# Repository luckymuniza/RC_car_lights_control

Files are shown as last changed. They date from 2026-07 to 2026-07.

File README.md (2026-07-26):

# RC Car Lights Control

Lighting controller for a large-scale RC truck. An RP2040 board sits between the
FlySky receiver and a **MFC-03** multi-function unit, reads the receiver's **iBUS**
stream directly, and drives the vehicle's LED lighting from it — while still letting the
MFC-03 keep control of the things it does best (sound, engine start-up sequence,
turn-signal timing, brake detection).

The MCU is both a *consumer* of the MFC-03 (it watches the MFC's own light and
turn-signal outputs) and a *producer* for it (it synthesises a servo signal into the MFC's
light channel so the MFC's internal "lights on" state stays in sync).

```
FlySky FS-i6X  ──2.4GHz──►  FS-iA6B RX ──┬── iBUS (UART, 115200) ──► RP2040 ──► LED outputs
                                          │                            ▲  │
                                          └── (channels) ──► MFC-03 ───┘  │
                                                                ▲          │
                                                                └──────────┘
                                                            synthesised servo signal
```

## Repository layout

| Path | Contents |
| --- | --- |
| `FW/` | Firmware — C, Raspberry Pi Pico SDK ≥ 2.1.0 |
| `HW/rccarcontrol/` | KiCad 9 project: schematic, PCB, gerbers, DRC report |
| `doc/` | MFC-03 manual, FS-i6X manual, output mapping spreadsheet, wiring manual |
| `sim/` | Multisim analog simulation (`Design1.ms14`) |

## Hardware

The board is built around a **USB-C RP2040 "Pico C" module** (`HW/.../rccarcontrol.kicad_sch`,
symbol `Pico_type_c`). Note this is *not* pin-compatible with a genuine Raspberry Pi Pico:
the module breaks out **GPIO29 on pad 35** and **GPIO23 on pad 37**, where a stock Pico has
`ADC_VREF` and `3V3_EN`. The firmware drives both of those pins, so it will not run
correctly on a stock Pico without remapping `FRONT_RAMP_LIGHT_OUT_PIN` and
`TURN_R_FRONT_OUT_PIN`.

Interfacing:

- **Inputs from the MFC-03** go through `EL3H7` optocouplers (U2–U8), so they are
  **active-low** and the firmware enables internal pull-ups on all of them.
- **Outputs** drive `IRLML0030` N-MOSFETs. Solder jumpers `JP3`–`JP7` select `+7V2_LED` or
  `+5V_LED` per LED group; `JP1`/`JP2` bring the receiver / external supply onto `+5V`.
- **Reverse light** (`REVERSE_LIGHT_IN`, opto U1) is wired straight to Q1/Q2 in hardware and
  never reaches the MCU — there is intentionally no firmware for it.

### Pin map

Verified against the PCB netlist. "Pad" is the module pad number.

**Outputs**

| GPIO | Pad | Net | Firmware | Type |
| --- | --- | --- | --- | --- |
| 0 | 1 | `LED_POWER` | `lights.c` | digital — master LED supply gate |
| 1 | 2 | `LOW_BEAM_OUT` | `lights.c` | digital |
| 2 | 4 | `HIGH_BEAM_OUT` | `lights.c` | digital |
| 3 | 5 | `FOG_LIGHT_OUT` | `lights.c` | digital |
| 4 | 6 | `AUX_1_OUT` | `aux1.c` | PWM slice 2A, 50 Hz servo, **inverted** polarity |
| 5 | 7 | `AUX_2_OUT` | `main.c` | digital — toggled every loop pass (loop-rate test point) |
| 6 | 9 | `TURN_R_PWM_OUT` | `turn_light.c` | PWM slice 3A, 2 kHz |
| 7 | 10 | `TURN_L_PWM_OUT` | `turn_light.c` | PWM slice 3B, 2 kHz |
| 8 | 11 | `TURN_L_FRONT_OUT` | `turn_light.c` | digital — short front-indicator pulse |
| 9 | 12 | `SEARCH_LIGHT_OUT` | `lights.c` | digital |
| 10 | 14 | `REAR_LIGHT_PWM_OUT` | `rear_light.c` | PWM slice 5A, 500 Hz |
| 11 | 15 | `SIDE_LIGHT_1_OUT` | `lights.c` | digital |
| 12 | 16 | `SIDE_LIGHT_2_OUT` | `lights.c` | digital |
| 13 | 17 | `RX_PWM_OUT` | `to_mfc.c` | PWM slice 6B, 50 Hz servo → MFC light channel |
| 14 | 19 | `BEACON_SMALL_PWM_OUT` | `beacons.c` | PWM slice 7A, 50 Hz servo |
| 15 | 20 | `BEACON_BIG_PWM_OUT` | `beacons.c` | PWM slice 7B, 50 Hz servo |
| 23 | 37 | `TURN_R_FRONT_OUT` | `turn_light.c` | digital |
| 25 | — | on-board LED | `main.c` | boot-blink only |
| 27 | 32 | `DAY_LIGHT_OUT` | `lights.c` | digital — on permanently after init |
| 28 | 34 | `POSITION_LIGHT_OUT` | `lights.c` | digital |
| 29 | 35 | `FRONT_RAMP_OUT` | `lights.c` | digital |

**Inputs** (all pulled up, active low)

| GPIO | Pad | Net | Firmware | Purpose |
| --- | --- | --- | --- | --- |
| 16 | 21 | `TURN_R_IN` | `turn_light.c` | MFC right indicator |
| 17 | 22 | `LIGHT_0_IN` | `lights.c` | configured, **not read** |
| 18 | 24 | `LIGHT_1_IN` | `lights.c` | MFC light state + start-up flash pattern |
| 19 | 25 | `LIGHT_2_IN` | `lights.c` | configured, **not read** |
| 20 | 26 | `LIGHT_3_IN` | `lights.c` | configured, **not read** |
| 21 | 27 | `RX_SBUS_IN` | `ibus.c` | UART1 RX — iBUS, 115200 8N1 |
| 22 | 29 | `TURN_L_IN` | `turn_light.c` | MFC left indicator |
| 26 | 31 | `REAR_BRAKE_IN` | `rear_light.c` | ADC0 — MFC rear/brake light level |

### Transmitter channel map

From `FW/ibus.h` (`ibus_channel`), 1-based as shown on the FS-i6X:

| Ch | Name | Used by |
| --- | --- | --- |
| 1 | Steering | — (passes to MFC directly) |
| 2 | MFC light channel | `to_mfc.c`, `aux1.c` |
| 3 | Throttle | — |
| 4 | Throttle X | — |
| 5 | Mode switch | `aux1.c` |
| 6 | Beacon switch | `beacons.c` |
| 7 | Gear switch | — |
| 8 | Light switch | `lights.c` |
| 9 / 10 | Pot A / Pot B | — |

Channels 1, 3, 4, 7 and the pots are declared but not consumed by the firmware.

## Firmware

### Structure

Cooperative, non-blocking super-loop. Every module exposes `*_init()` (called once) and
`*_service()` (called every pass, returns immediately). No RTOS, no blocking delays after
start-up, no dynamic allocation. All timing uses `time_us_32()` deadlines compared as
signed differences, so 32-bit wrap is handled correctly.

| Module | Responsibility |
| --- | --- |
| `main.c` | Boot blink, init order, super-loop |
| `ibus.c` | iBUS frame decoding — the only interrupt-driven part |
| `lights.c` | Light-state machine, side lights, MFC light-state sync, start-up flash replay |
| `turn_light.c` | Indicator soft fade-in / fade-out driven by MFC edges |
| `rear_light.c` | Tail / brake light PWM, ADC brake detection |
| `beacons.c` | Rotating beacons, fog + search light, beacon configuration mode |
| `to_mfc.c` | Synthesised servo output back into the MFC light channel |
| `aux1.c` | Diverts the light channel to an auxiliary servo output (crane) |
| `switch.h` | Shared 3-position-switch state machine constants |

### iBUS decoder

`ibus.c` decodes the standard 32-byte FlySky iBUS servo frame:

```
0x20 0x40 <14 × uint16 LE channel values> <uint16 LE checksum>
```

The checksum is validated by summing all 32 bytes and requiring `0xFFFF`. Frame
synchronisation is done by **inter-byte gap**, not by header alone: a byte arriving more
than `SBUS_NEXT_FRAME_TIMEGAP` (3 ms) after the previous one is treated as a frame start.
Frames arrive roughly every 7 ms and each takes ~2.7 ms, so the gap is unambiguous.

The ISR writes into `channel_data`; `ibus_service()` copies it to `channel_data_saved`
with interrupts disabled, and `ibus_get_channel()` reads only the snapshot.

### Light state machine (`lights.c`)

Channel 8 acts as a momentary 3-position switch. Short pull **up** steps forward, holding
up for >1 s steps back:

```
OFF ──► POSITION ──► LOW_BEAM ──► HIGH_BEAM ──► RAMP
    ◄──          ◄──          ◄──           ◄──          (hold >1 s)
```

Pushing **down** flashes the front ramp light for as long as it is held.

Side lights (`SIDE_LIGHT_1/2`) have their own state: off, on with the position lights, a
double-flash alternating beacon pattern (when the rotating beacons are on), or a slow
0.5 s blink to indicate beacon-configuration mode.

### MFC light-state sync

The MFC-03 beeps when the engine is switched off with its lights still on, so its internal
state must track the real one. `update_lights_in_mfc()` compares `l_state` against
`LIGHT_1_IN` and, when they disagree, asks `to_mfc.c` to emit one 100 ms pulse train on the
synthesised light channel — the equivalent of one stick flick. It repeats every 0.5 s until
the states match.

### Start-up flash replay

On engine start the MFC-03 flashes its light output rapidly. `detect_starting_seq()`
detects this (edges closer than 25 ms apart), records the on/off durations into a 64-entry
ring buffer — duration in bits 0–14, level in bit 15 — and replays them onto `LED_POWER`
so the real headlights flicker in step with the MFC's simulated start-up. While the replay
is active, MFC light-state sync is suspended.

### Turn signals

The MFC drives the blink timing; the firmware only reshapes it. On each falling edge of
`TURN_L_IN` / `TURN_R_IN` it pulses the front indicator hard for 100 ms and simultaneously
ramps the PWM channel up (100 counts / 10 ms), holds at full for 100 ms, then ramps down
(50 counts / 7.5 ms) — roughly a 600 ms incandescent-style fade. Re-triggering is ignored
while a fade is still running.

### Rear / brake light

`REAR_BRAKE_IN` is sampled on ADC0 through a 32-sample moving average. Below
`REAR_LIGHT_BRAKE_LEVEL` the tail light PWM goes to full (brake); otherwise it follows the
main light state at 25 % duty, or off.

### Beacons

Two servo-protocol beacon outputs, driven as if by a stick:

- **Short pull up** — both beacons on, side lights switch to the alternating flash pattern.
- **Hold up >1 s** — both off. The small beacon has to be cycled through all four of its
  internal modes to reach off, which `beacon_small_off()` does with eight 50 ms pulses.
- **Hold up >5 s** — enter configuration mode: big beacon on, side lights blink slowly. In
  config, short up = next mode, short down = next brightness, hold up >5 s = exit.
- **Short pull down** — cycles the rear search light and the fog light. Hold down >1 s
  turns both off. The fog light only comes on if the main lights are on.

### Auxiliary output

When channel 5 is above 1800, `aux1.c` mirrors the channel-2 value onto `AUX_1_OUT`
(inverted polarity) for a crane servo, and tells `to_mfc.c` to park the MFC light channel at
centre so the MFC ignores it.

## Building

Requires the Raspberry Pi Pico SDK **2.1.0 or later**, `arm-none-eabi-gcc`, CMake ≥ 3.12
and `picotool`.

```sh
export PICO_SDK_PATH=/path/to/pico-sdk
cd FW
cmake -B build -DCMAKE_BUILD_TYPE=Debug
cmake --build build
```

Output is `build/car_lighting.uf2` (plus `.elf`, `.bin`, `.hex`, `.map`). The build prints
memory usage and a section size summary.

`CMakeLists.txt` hardcodes `picotool_DIR` to a local absolute path; override it with
`-Dpicotool_DIR=...` or edit it if picotool lives elsewhere. `stdio` over both USB and UART
is disabled — GPIO0/GPIO1 are used as light outputs, so UART0 is unavailable. To get printf
debugging you must free those pins first.

## Flashing

Hold `BOOTSEL` while plugging the board in and copy the `.uf2` to the `RPI-RP2` drive.

`FW/up.bat` automates this on Windows: it pokes the USB CDC port at 1200 baud to force the
board into BOOTSEL, finds the `RPI-RP2` volume and copies the image. It references helper
tools under `f:\_Work\_Programing\rpi\` and expects the artefact in
`cmake-build-debug-system-arm\`, so the paths need adjusting for the current build
directory before it will work.

## Known limitations

- **No receiver failsafe.** `ibus_get_channel()` returns the last valid frame forever. If
  the link drops, the lighting freezes in its last state and the synthesised MFC channel
  keeps repeating a stale value.
- **Boot blocks on iBUS.** `main()` spins in `while (!ibus_data_valid())` before any
  outputs are initialised, so with no receiver signal the board never leaves start-up.
- **No watchdog.**
- `LIGHT_0_IN`, `LIGHT_2_IN`, `LIGHT_3_IN` are wired and configured but unused.

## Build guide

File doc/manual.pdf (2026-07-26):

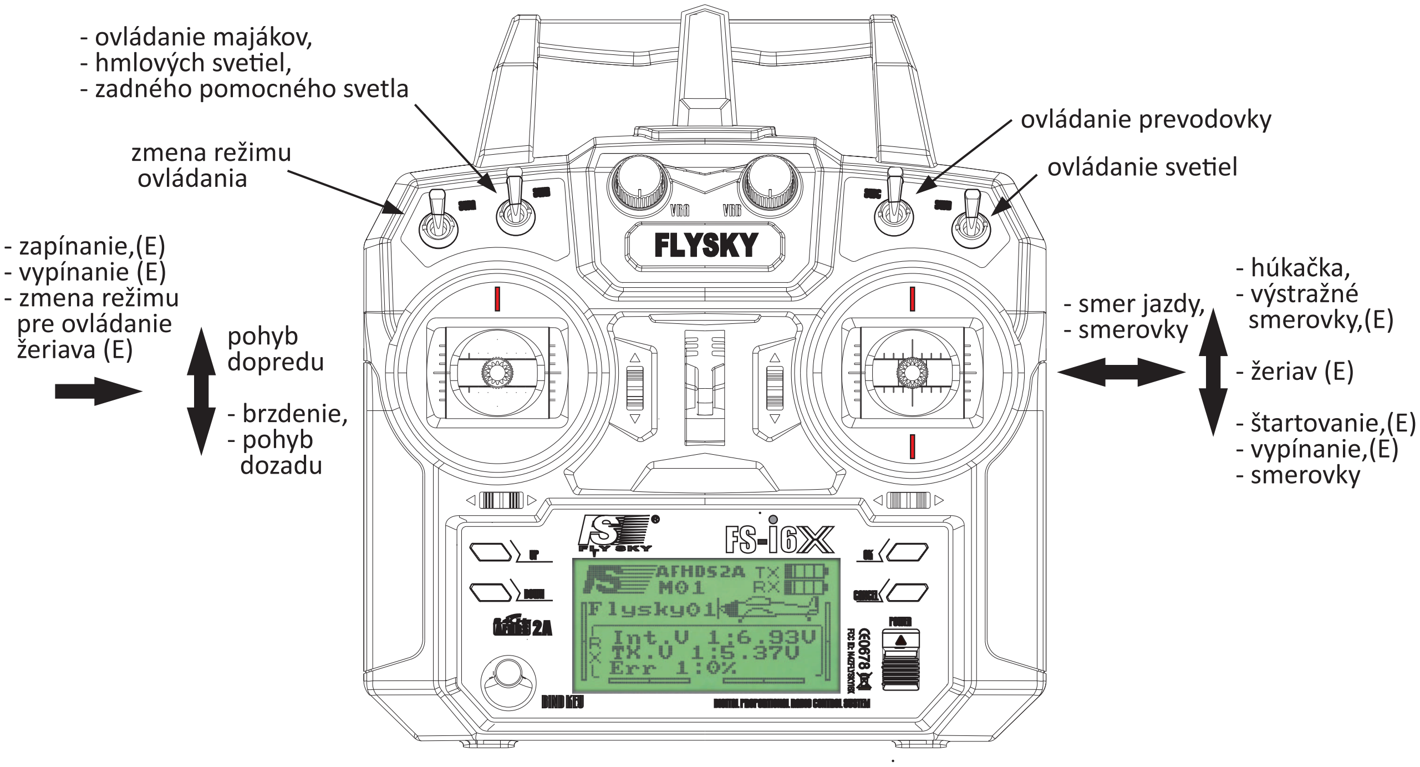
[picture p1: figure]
ž mena re imu; ovl dania á; - ovládanie majákov, - hmlových sve%el, - zadného pomocného svetla; ovládanie prevodovky; ovládanie sve%el; - smer jazdy, - smerovky; - húkačka, - výstražné smerovky,(E); - žeriav (E); - štartovanie,(E) - vypínanie,(E) - smerovky; - zapínanie,(E) - vypínanie (E) - zmena režimu pre ovládanie; žeriava (E); pohyb; dopredu; - brzdenie, - pohyb dozadu

Z | ž | á | . mena re imu ovl dania
Normálny režim - | loha od seba. V tomto režime sa auto normálne ovláda (pohyb dopredu, po
dozadu, a ostatné funkcie)

Extra režim 1 - loha neutrálna. vo vysielači je označený ako SPORT. po
V tomto režime majú niektoré kniple ďalšie funkcie. V popise hore sú označené (E)

Extra režim 2 - loha smerom k sebe. To isté ako Extra režim ale v tomto režim pravý knipel po ovláda priamo žeriav. Toto funguje vtedy ak by sa pripojilo ovládanie žeriavu do rozširujúceho modulu, nie do MFC-03 ako to je. Ak je ovládanie pripojené do MFC-03 ovláda sa cez Extra režim 1.

## Z prevodového stupňa. mena

Stupeň 1

Stupeň 2

Stupeň 3

## Popis ovládania sve$el pre Volvo Fh16 s modulom MFC-03

## Ovládanie majákov, hmlových sve$el, zadného pomocného svetla, sve!el

> 0.01s ON
1s> | OFF | zapnu$e - podržať v polohe min 0,01s a vrá%ť späť vypnu$e - podržať v polohe rovnakej ako pri zapínaní min 1s a vrá%ť späť,
Majáky | polohe k sebe - podržať v | vrá%ť späť. Pri zapnutých majákoch blikajú striedavo
bočné svetlá 1 a 2 (4ks + 4ks) na jednej a druhej strane
Hmlové a Zadné pomocné svetlá | v polohe odseba - podržať | vrá%ť späť
Pri zapínaní sa zapínaju svetlá v takomto poradí: 1.iba zadné pomocné
2.iba hmlové
3 hmlové + zadné pomocné
Ak nesvie%a hlavné svetlá (aspoň pozičné) nedajú sa hmlové zapnúť
Pozičné, stretávacie, diaľkové, rampa | v polohe k sebe - podržať | vrá%ť späť
Pri zapínaní sa postupne rozsvecujú svetlá v takomto poradí:
1. pozičné
2. + stretávacie + zadné + bočné
3. + diaľkové
4. + horná rampa
Postupným zapínaním sa rozsvecujú ďalšie svetlá. Pri vypínaní sa zhášajú v opačnom poradí.

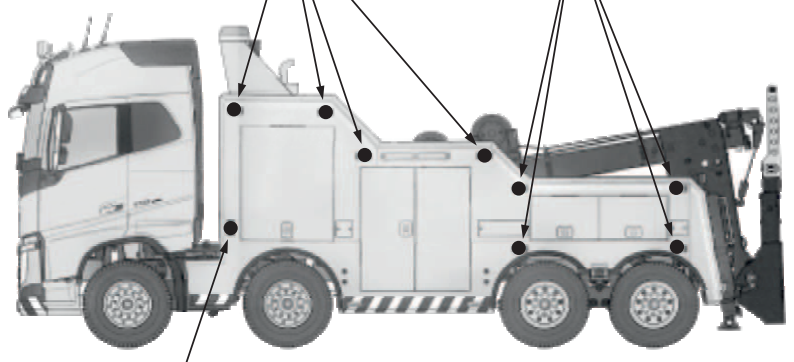
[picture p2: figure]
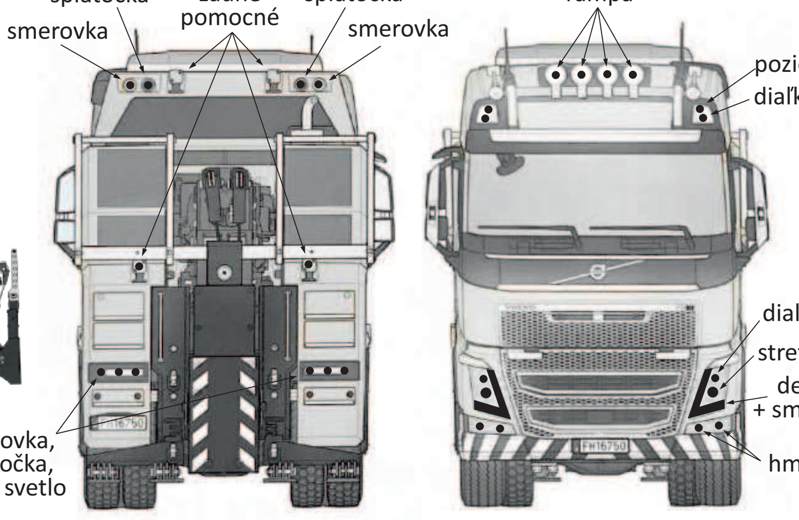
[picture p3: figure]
pomocné; smerovka

Rampa ako svetelná húkačka | v polohe od seba - podržať | . Svie%počas držania vypínača v polohe.
Konfigurácia veľkého majáku | polohe k sebe - podržať v | viac ako 5s. Maják sa zapne a blikajú
bočné svetlá. Jednotlivé módy | ó | sa potom prepínajú krátkym podr - 18 m dov | žaním ( 0,01s) v >
polohe k sebe a jas - 3 úrovne sa prepínajú krátkym podržaním ( 0,01s) | . > | polohy od seba
Ukončenie konfigurácie sa dosiahne podržaním v | na viac ako 5s. Maják a polohe k sebe
bočné svetlá prestanú blikať.
Mód | Jas
> | ON 5s Konf.
> | OFF 5s Konf.

## Rozmiestnenie svie$diel

bočné
svetlá 1

zadné

bočná
smerovka

spiatočka
spiatočka

smerovka,
spiatočka,
zadné svetlo

rampa

pozičné
diaľkové
bočné
svetlá 2

denné
+ smerovka

stretávacie

hmlové

diaľkové

norm lá ny
režim
Štartovanie - normálny režim zapnutý, ravý knipel k sebe. Ak sa posunie knipel p na doraz a podrží určitú dobu motor naštartuje, ak sa podrží niekde medzi krajnou polohou a neutrálnou polohou motor bude štartovať pokiaľ sa knipel neposunie do krajnej polohy. Pred štartovaním je potrebné vykonať zapnu%e zapaľovania ak bolo predtým vypnuté. Po prvom zapnu* prijímača nie je potrebné ,môže sa hneď štartovať.

extra
režim
Vypnu$e motora - extra režim zapnutý, súčasne ľavý knipel doprava, ravý p knipel k sebe a uvoľniť. Ak ostali zapnuté svetlá, modul pípa.

Zapnu$e zapaľovania po vypnu' - to isté ako vypnu%e motora, extra režim
zapnutý, ľavý knipel doprava, ravý knipel k sebe a uvo p | ľniť. Je nutné vykonať
pred štartovaním ak sa predtým vykonalo vypnu%e motora.

Pred spustením - vypínače musia byť v polohe od seba a ľavý knipel v polohe k sebe. Inak vysielač nedovolí ovládanie. Tie dva ktoré sa vracajú do neutrálnej polohy sa %ež musia podržať v polohe odseba.

Smerovky - normálny režim, najprv pravý knipel úplne k sebe a uvoľniť. Potom posunúť do tej strany na ktorú má svie%ť smerovka. Ak sa posunie knipel úplne do krajnej polohy, doľava alebo doprava, smerovka sa vypne keď sa posunie do neutrálu. Keď sa posunie len do polovice ustane zapnutá. Vypne sa opätovným pri%ahnu*m knipla k sebe.

norm lá ny
režim

1

3 | 3
| 2
1 | 2

1

2

1 2

Výstražné smerovky - Extra režim, Pravý knipel od seba a uvoľniť. to isté zopakovať pre vypnu%e smeroviek. ¹ 2

extra
režim

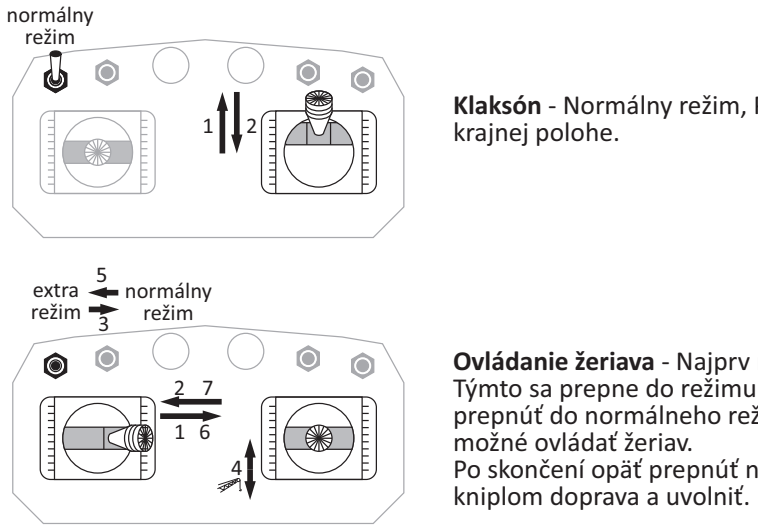
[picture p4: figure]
krajnej polohe. ¹; norm lá ny režim; možné ovládať žeriav.; kniplom doprava a uvolniť.; extra režim

Klaksón - Normálny režim, Pravý knipel od seba. Klaksón trúbi pokiaľ je knipel v

Ovládanie žeriava - Najprv nastaviť extra režim. Ľavý knipel doprava a uvoľniť. Týmto sa prepne do režimu ovládania žeriavu pravým kniplom. Extra režim prepnúť do normálneho režimu a pravým kniplom od seba a k sebe je potom

Po skončení opäť prepnúť na extra režim a ukončiť ovládanie žeriavu ľavým

Ovládanie ďalších funkcií | MFC-03 - funkcie

Ovládanie žeriava - Je možné aj priamo v režime Extra 2 ale je potrebné inak zapojiť ovládanie žeriavu.

extra
režim 2

Zmena zvuku smeroviek - Extra režim a zapnúť výstražné smerovky. Potom pravý knipel k sebe, doľava a uvoľniť. Takto sa prepne iný typ zvuku smeroviek. Na výber sú dva typy.

extra
režim

1

2

Zmena klaksónu - Extra režim. Potom ľavý knipel doľava a uvoľniť. Takto sa prepne iný typ zvuku klaksónu.
Na výber sú dva typy.

extra
režim

1

2

Odfúknu$e - Normálny režim. Pravý knipel držať k sebe. Potom ľavý knipel kúsok (10%) k sebe a uvoľniť. Môže sa zopakavať.

1

2

norm l á ny
režim

10%

3

norm l á ny
režim

Režim spojky - Normálny režim. Pravý knipel funguje ako spojka, čím je viac k sebe tým je akoby spojka viac stlačená - motor ide naprázdno, rýchlejšie ide do otáčok (zvuk) ako keď je v neutrálnej polohe.

Nastavenie vysielača.

Keďže MFC-03 dokáže spracovaťsignály len zo 4 kanálov. Pre prepnu%eďalších funkcií týchto 4 kanálov sa využíva toho že v normálnom režime sú hodnoty kanálov od -100% po + 100%. Ale ak sa použije trim a posunie sa do krajnej polohy potom hodnota kanálu môže ísť až napr. od -120% po +120%. Takže ak MFC-03 zis* že vysielač posiela hodnotu 120% pova uje ž ju za ďalšiu možnosť alebo prepnu%e inej funkcie. Vysielač FLYSKY má digitálne trimre a prepínať trimrami %eto ďalšie funkcie by bolo komplikované - je potrebné čo najrýchlejšie nastaviť trim do krajnej polohy. Preto sa využívaju dvojité výchylky na vysielači. Na vysielači sú nastavené dva režimy NORMAL a SPORT ktorý má nastavené pre konkrétne kanály dvojité výchylky. V tomto prípade pre ľavý knipel 4. kanál a pravý knipel 1. a 2. kanál. Takže ľavý vypínač - prepínač režimu, v normalnom režime na vysielači nastavý režim NORMAL a v Extra 1 je prepnutý na vysielači režim SPORT a v Extra 2 je%ežrežim SPORT. V režime NORMAL sú hodnoty kanálo 1,2,4 pri plnom vychýlení knipla len
do 75% | %. . V režime Extra do 100 | Čiže ak by bol zapnuty režim Extra tak ak by sa s kniplom išlo len do 75% vychýlenia
bolo by to ako v režime NORMAL. Napr. klaksón a výstražné smerovky. Pravý knipel od seba sa zapínajú výstražné smerovky ale aj klaksón. Lenže klaksón je v normálnom režime 75% hodnota, a smerovky v Extra režime 100%. Takže ak je zapnutý extra režim a knipel sa vychýli do 75% zatrúbi klaksón.
K.4 | K.1

K.2

K.3

K.5 | K.6 | K.7 K.8
K.9 | K.10

Rozmiestnenie kanálov na vysielači - MÓD 2 Vo vysielači nastavené v menu SYSTÉM: S!ck Mode -> MODE 2
RX setup -> Output mode -> PWM, I-BUS AUX switches -> SWA ON, SWB ON, SWC ON, SWD ON,
VrA ON, VrB ON,
CH 10

v menu FUNCTION SETUP:
Reverse -> všetky kanály NORMAL
End Points - v > šetky kanály 100%, pre kanál 7 - servo prevodovky, treba nastaviť koncové body podľa potreby AUX channels - Channel 5 - SwA >
Channel 6 - SW B
Channel 7 - SW C
Channel 8 - SW D
Channel 9 - VrA
Channel 10 -VrB
Subtrim -> v | 0 šetky kanlály
Dual rate - K.1, 2, 4 re > | žim NORMAL rate 75%
režim SPORT rate 100%
Asign Switches - | - > Fly mode > SwA
prep | . V ínanie módu NORMAL / SPORT | popise Normálny režim a Extra režim. Extra režim 2 je vo
vysielači to isté ako ako Extra režim, rozlišuje sa až v prídavnom module).
Ostatn nastavenia é | štandartné.
Pre MFC-03 je potrebné urobiť kalibráciu rozsahu kanálov v normálnom režime - %eto sú pre MFC-03 100%
v chylky ý . Podľa manuálu MFC-03. Podržať spínač na MFC-03 medzi 1 až 3 s - začnú blikať smerovky. potom posunúť z krajnej polohy ľavý knipel zhora dole, potom ľavý knipel zprava do ľava, pravý knipel zhora dole a pravý knipel z prava do ľava. Potom prestanú blikať smerovky, tak ešte raz stlačiť tlačítko. Výchylky pre trim nie je potrebné kalibrovať (a ťažko by sa to v takejto konfigurácii s digitálnymi trimrami).

## Pomocn modul ý

Pomocný modul je na to aby bolo možné použiť viac funkcií vysielača, a jednoduchšie ovládanie. Takto sa využívajú všetky vypínače. Tie sú všetky trojpolohové. Potenciometre sa nevyužívajú (Takže ešte ostali volné kanály 9,10). MFC-03 funguje len na zvuk, sekvencie pri štartovaní, brzdenie, spiatočka, smerovky. Ovládanie majákov a sve%el je cez prídavný modul. Ale je zachované blikanie sve%el pri štartovaní a pípanie pri vypnu* motora. Smerovky pre predné svetlá sú%ežsynchronizované s MFC-03. Keďže je teraz viac lediek tak všetky spína prídavný modul. Aby bolo spínanie sve%el synchronizovné s MFC-03 prídavný modul emuluje spínacie sekvencie sve%el v MFC-03, takže zapnu%e sve%el v MFC-03 a v prídavnom module je synchronizované. To je len kôli tomu že keď sa motor vypne tak pípa že svie%a svetlá. a ešte kvôli tomu efektu že keďsa štartuje tak sa simuluje pokles napa%a - to robí ten MFC-03. Ěšte je pridaný taký efekt že smerovky blikajú ako žiarovky, pomaly sa zhášajú. Pre veľký maják sa dá zmeniť mód aj jas.Malý maják má %ež 4 módy blikania lenže tam je problém s vypínaním nevypína sa ako ten veľký maják hodnotou kanála ale prepínaním módov. Na začiatku je hneď zapnutý takže treba poprepínať všetky 4 módy aby zhasol - lepšie by bolo ho vypínať napájaním. Ale to vypnu%e robí automa%cky ten modul takže neni toto treba absolvovať. Len užsa nedá vybrať mód. Je tam mód 1, taký že ako keby sa točilo svetlo vnútri majáku.
Ostali ešte dva pomocné výstupy voľné AUX1, AUX2, môžu niečo spínať ak by bolo treba. Hodnota všetkých kanálov z vysielača sa získava z prijímača cez I-BUS zbernicu.
Napájaný je z hlavnej batérie a je ešte doplnený zdroj aby udržiaval stále napä%e 7,2V aj keď napä%e batérie klesne na nižšiu hodnotu. zapínaťsa nemusí, zapne sa keďsa zapne MFC-03.

Schéma zapojenia.

## MFC-03

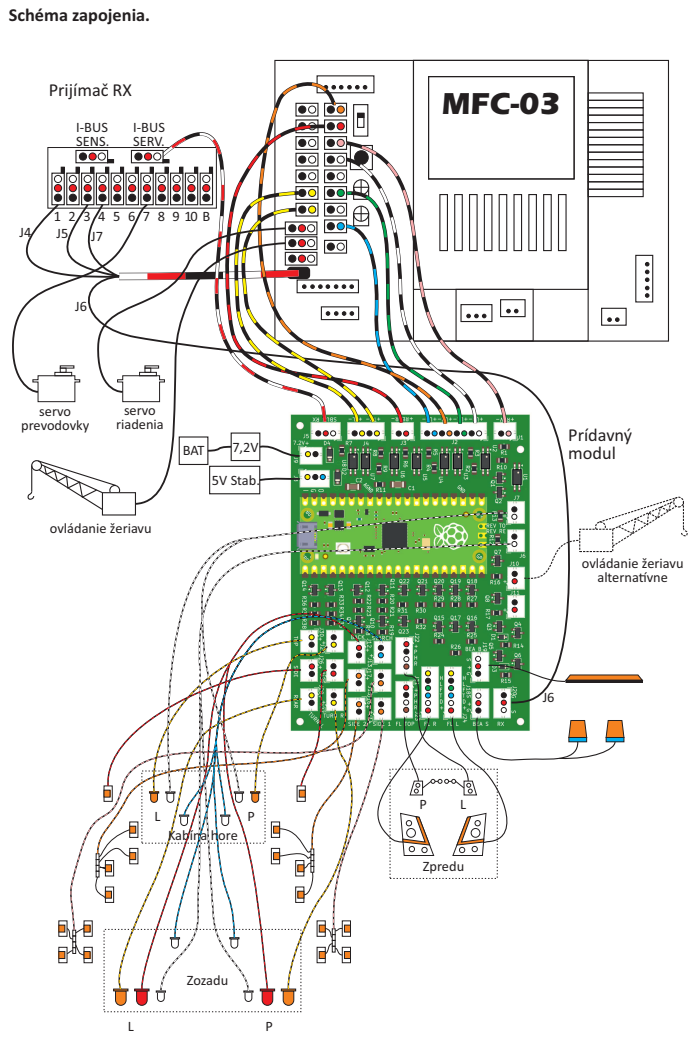
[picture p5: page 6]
I-BUS SERV.; Prijímač RX; 5V Stab.; Kabína hore; Zozadu; Zpredu; servo prevodovky; servo riadenia; ovl anie eriavu ád; Prídavný modul; alterna*vne; BAT; I-BUS SENS.

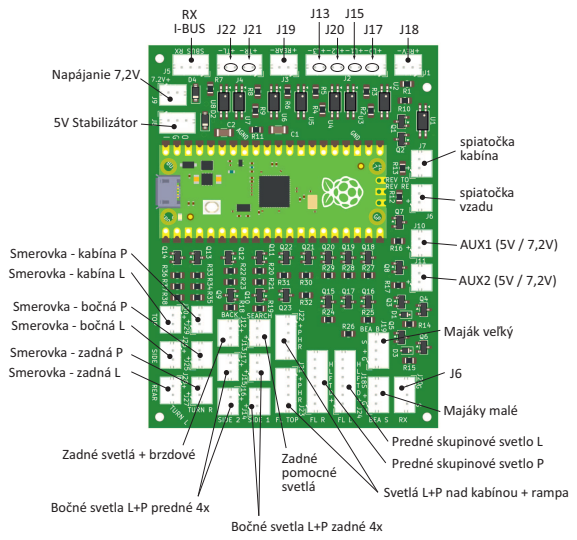
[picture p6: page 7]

Svetlá L+P nad kabínou + rampa

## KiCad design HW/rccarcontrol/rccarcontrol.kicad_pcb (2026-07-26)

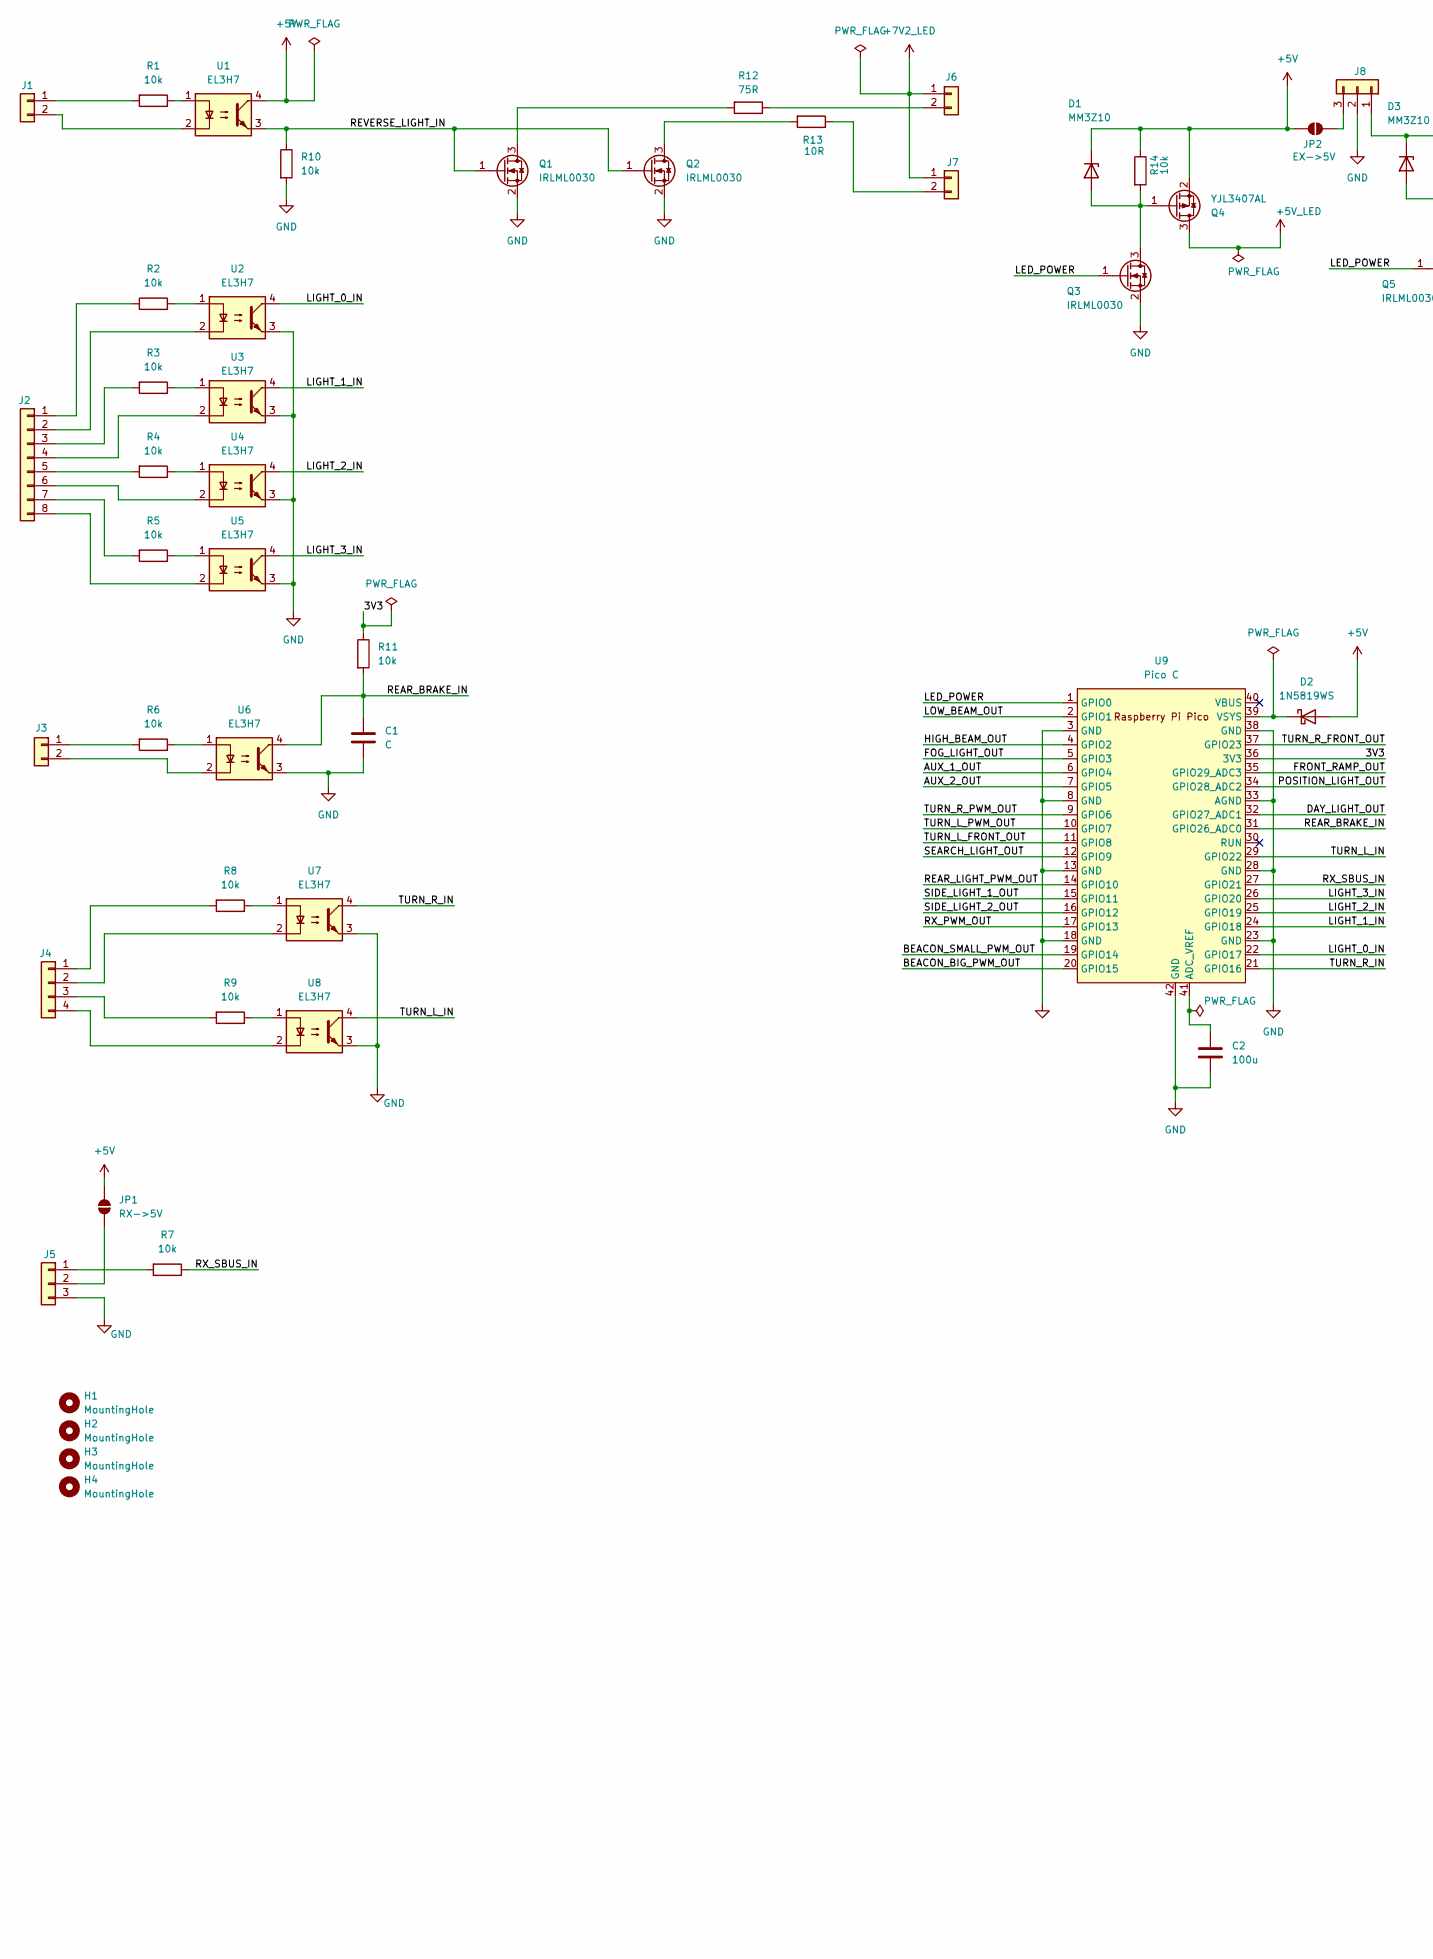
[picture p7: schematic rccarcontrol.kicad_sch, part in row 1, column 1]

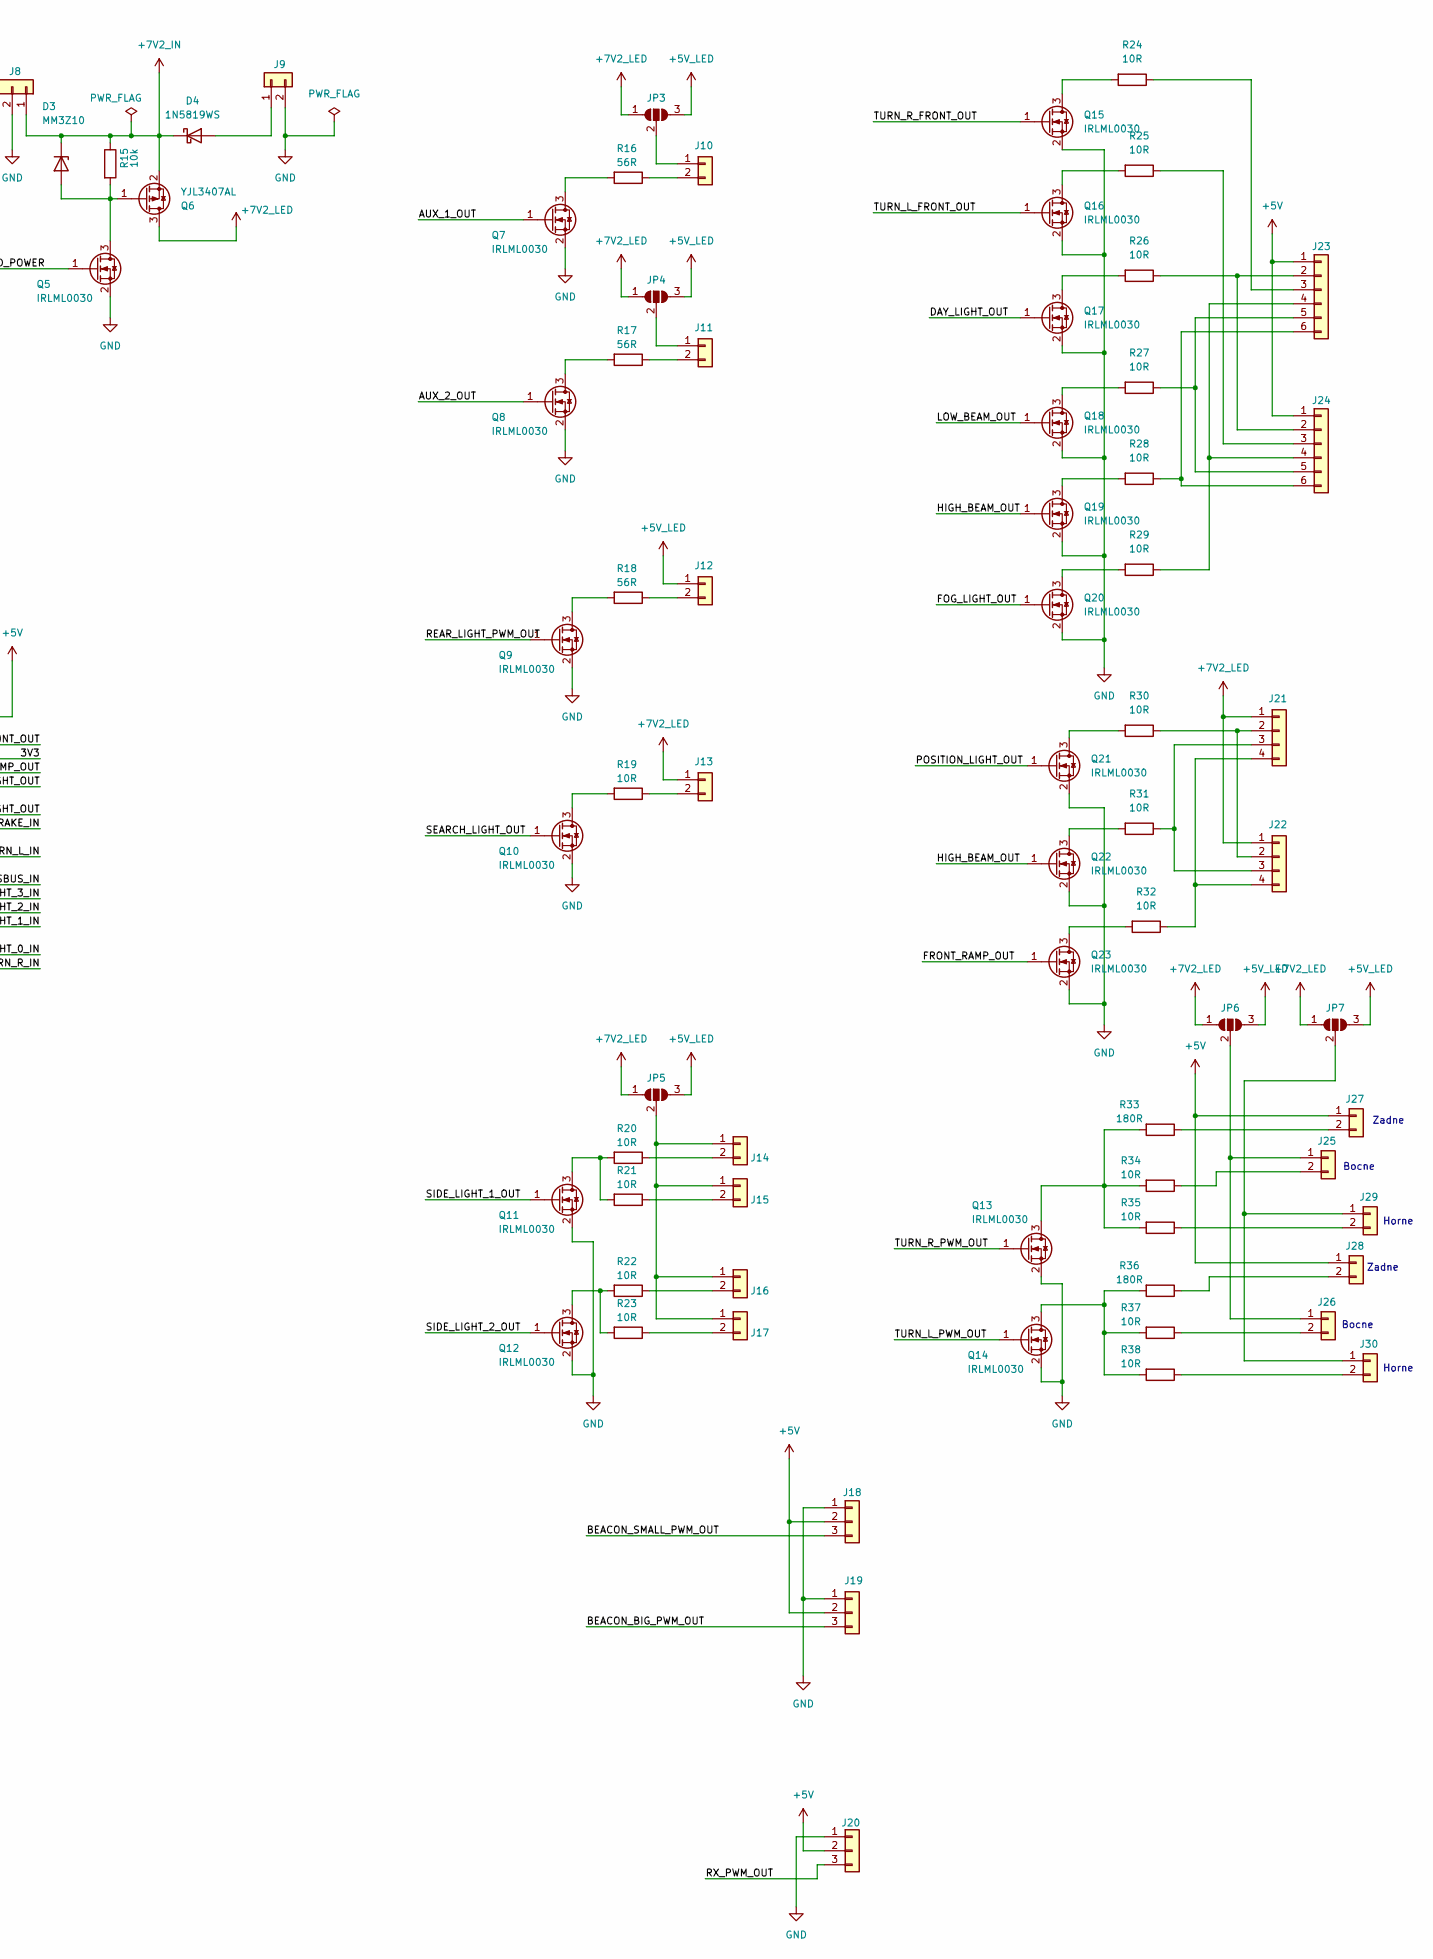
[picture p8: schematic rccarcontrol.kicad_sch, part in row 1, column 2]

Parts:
C1: C; C_1206_3216Metric_Pad1.33x1.80mm_HandSolder
C2: 100u; C_1206_3216Metric_Pad1.33x1.80mm_HandSolder
D1, D3: MM3Z10; D_SOD-323F
D2, D4: 1N5819WS; D_SOD-123
H1, H2, H3, H4: MountingHole; MountingHole_2mm
J1, J3, J6, J7, J9, J10, J11, J12, J13, J14, J15, J16, J17, J25, J26, J27, J28, J29, J30: Conn_01x02; JST_PH_B2B-PH-K_1x02_P2.00mm_Vertical
J2: Conn_01x08; JST_PH_B8B-PH-K_1x08_P2.00mm_Vertical
J4, J21, J22: Conn_01x04; JST_PH_B4B-PH-K_1x04_P2.00mm_Vertical
J5, J8, J18, J19, J20: Conn_01x03; JST_PH_B3B-PH-K_1x03_P2.00mm_Vertical
J23, J24: Conn_01x06; JST_PH_B6B-PH-K_1x06_P2.00mm_Vertical
JP1: RX->5V; SolderJumper-2_P1.3mm_Open_RoundedPad1.0x1.5mm
JP2: EX->5V; SolderJumper-2_P1.3mm_Open_RoundedPad1.0x1.5mm
JP3, JP4, JP5, JP6, JP7: SolderJumper_3_Open; SolderJumper-3_P1.3mm_Open_RoundedPad1.0x1.5mm_NumberLabels
Q1, Q2, Q3, Q5, Q7, Q8, Q9, Q10, Q11, Q12, Q13, Q14, Q15, Q16, Q17, Q18, Q19, Q20, Q21, Q22, Q23: IRLML0030; SOT-23-3
Q4, Q6: YJL3407AL; SOT-23-3
R1, R2, R3, R4, R5, R6, R7, R8, R9, R10, R11, R14, R15: 10k; R_0805_2012Metric_Pad1.20x1.40mm_HandSolder
R12: 75R; R_0805_2012Metric_Pad1.20x1.40mm_HandSolder
R13, R19, R20, R21, R22, R23, R24, R25, R26, R27, R28, R29, R30, R31, R32, R34, R35, R37, R38: 10R; R_0805_2012Metric_Pad1.20x1.40mm_HandSolder
R16, R17, R18: 56R; R_0805_2012Metric_Pad1.20x1.40mm_HandSolder
R33, R36: 180R; R_0805_2012Metric_Pad1.20x1.40mm_HandSolder
U1, U2, U3, U4, U5, U6, U7, U8: EL3H7; SOP-4_4.4x2.6mm_P1.27mm
U9: Pico C; RPi_Pico_type_c_SMD_TH

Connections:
+5V: D1.1 (K), D2.2 (A), J18.2, J19.2, J20.2, J23.1, J24.1, J27.1, J28.1, JP1.2 (B), JP2.2 (B), Q4.2 (S), R14.1, U1.4
+5V_LED: J12.1, JP3.3 (B), JP4.3 (B), JP5.3 (B), JP6.3 (B), JP7.3 (B), Q4.3 (D)
+7V2_IN: D3.1 (K), D4.1 (K), J8.1, Q6.2 (S), R15.1
+7V2_LED: J6.1, J7.1, J13.1, J21.1, J22.1, JP3.1 (A), JP4.1 (A), JP5.1 (A), JP6.1 (A), JP7.1 (A), Q6.3 (D)
/3V3: R11.1, U9.36 (3V3)
/AUX_1_OUT: Q7.1 (G), U9.6 (GPIO4)
/AUX_2_OUT: Q8.1 (G), U9.7 (GPIO5)
/BEACON_BIG_PWM_OUT: J19.3, U9.20 (GPIO15)
/BEACON_SMALL_PWM_OUT: J18.3, U9.19 (GPIO14)
/DAY_LIGHT_OUT: Q17.1 (G), U9.32 (GPIO27_ADC1)
/FOG_LIGHT_OUT: Q20.1 (G), U9.5 (GPIO3)
/FRONT_RAMP_OUT: Q23.1 (G), U9.35 (GPIO29_ADC3)
/HIGH_BEAM_OUT: Q19.1 (G), Q22.1 (G), U9.4 (GPIO2)
/LED_POWER: Q3.1 (G), Q5.1 (G), U9.1 (GPIO0)
/LIGHT_0_IN: U2.4, U9.22 (GPIO17)
/LIGHT_1_IN: U3.4, U9.24 (GPIO18)
/LIGHT_2_IN: U4.4, U9.25 (GPIO19)
/LIGHT_3_IN: U5.4, U9.26 (GPIO20)
/LOW_BEAM_OUT: Q18.1 (G), U9.2 (GPIO1)
/POSITION_LIGHT_OUT: Q21.1 (G), U9.34 (GPIO28_ADC2)
/REAR_BRAKE_IN: C1.2, R11.2, U6.4, U9.31 (GPIO26_ADC0)
/REAR_LIGHT_PWM_OUT: Q9.1 (G), U9.14 (GPIO10)
/REVERSE_LIGHT_IN: Q1.1 (G), Q2.1 (G), R10.1, U1.3
/RX_PWM_OUT: J20.3, U9.17 (GPIO13)
/RX_SBUS_IN: R7.1, U9.27 (GPIO21)
/SEARCH_LIGHT_OUT: Q10.1 (G), U9.12 (GPIO9)
/SIDE_LIGHT_1_OUT: Q11.1 (G), U9.15 (GPIO11)
/SIDE_LIGHT_2_OUT: Q12.1 (G), U9.16 (GPIO12)
/TURN_L_FRONT_OUT: Q16.1 (G), U9.11 (GPIO8)
/TURN_L_IN: U8.4, U9.29 (GPIO22)
/TURN_L_PWM_OUT: Q14.1 (G), U9.10 (GPIO7)
/TURN_R_FRONT_OUT: Q15.1 (G), U9.37 (GPIO23)
/TURN_R_IN: U7.4, U9.21 (GPIO16)
/TURN_R_PWM_OUT: Q13.1 (G), U9.9 (GPIO6)
GND: C1.1, C2.1, J5.3, J8.2, J9.2, J18.1, J19.1, J20.1, Q1.2 (S), Q2.2 (S), Q3.2 (S), Q5.2 (S), Q7.2 (S), Q8.2 (S), Q9.2 (S), Q10.2 (S), Q11.2 (S), Q12.2 (S), Q13.2 (S), Q14.2 (S), Q15.2 (S), Q16.2 (S), Q17.2 (S), Q18.2 (S), Q19.2 (S), Q20.2 (S), Q21.2 (S), Q22.2 (S), Q23.2 (S), R10.2, U2.3, U3.3, U4.3, U5.3, U6.3, U7.3, U8.3, U9.3 (GND), U9.8 (GND), U9.13 (GND), U9.18 (GND), U9.23 (GND), U9.28 (GND), U9.33 (AGND), U9.38 (GND), U9.42 (GND)
unnamed: D1.2 (A), Q3.3 (D), Q4.1 (G), R14.2
unnamed: D2.1 (K), U9.39 (VSYS)
unnamed: D3.2 (A), Q5.3 (D), Q6.1 (G), R15.2
unnamed: D4.2 (A), J9.1
unnamed: J1.1, R1.2
unnamed: J1.2, U1.2
unnamed: J2.1, R2.1
unnamed: J2.2, U2.2
unnamed: J2.3, R3.2
unnamed: J2.4, U3.2
unnamed: J2.5, R4.2
unnamed: J2.6, U4.2
unnamed: J2.7, R5.2
unnamed: J2.8, U5.2
unnamed: J3.1, R6.2
unnamed: J3.2, U6.2
unnamed: J4.1, R8.2
unnamed: J4.2, U7.2
unnamed: J4.3, R9.2
unnamed: J4.4, U8.2
unnamed: J5.1, R7.2
unnamed: J5.2, JP1.1 (A)
unnamed: J6.2, R12.1
unnamed: J7.2, R13.1
unnamed: J8.3, JP2.1 (A)
unnamed: J10.1, JP3.2 (C)
unnamed: J10.2, R16.1
unnamed: J11.1, JP4.2 (C)
unnamed: J11.2, R17.1
unnamed: J12.2, R18.1
unnamed: J13.2, R19.1
unnamed: J14.1, J15.1, J16.1, J17.1, JP5.2 (C)
unnamed: J14.2, R20.1
unnamed: J15.2, R21.1
unnamed: J16.2, R22.1
unnamed: J17.2, R23.1
unnamed: J21.2, J22.2, R30.1
unnamed: J21.3, J22.3, R31.1
unnamed: J21.4, J22.4, R32.1
unnamed: J23.2, J24.2, R26.1
unnamed: J23.3, R24.1
unnamed: J23.4, J24.4, R29.1
unnamed: J23.5, J24.5, R27.1
unnamed: J23.6, J24.6, R28.1
unnamed: J24.3, R25.1
unnamed: J25.1, J26.1, JP6.2 (C)
unnamed: J25.2, R34.1
unnamed: J26.2, R37.1
unnamed: J27.2, R33.1
unnamed: J28.2, R36.1
unnamed: J29.1, J30.1, JP7.2 (C)
unnamed: J29.2, R35.1
unnamed: J30.2, R38.1
unnamed: Q1.3 (D), R12.2
unnamed: Q2.3 (D), R13.2
unnamed: Q7.3 (D), R16.2
unnamed: Q8.3 (D), R17.2
unnamed: Q9.3 (D), R18.2
unnamed: Q10.3 (D), R19.2
unnamed: Q11.3 (D), R20.2, R21.2
unnamed: Q12.3 (D), R22.2, R23.2
unnamed: Q13.3 (D), R33.2, R34.2, R35.2
unnamed: Q14.3 (D), R36.2, R37.2, R38.2
unnamed: Q15.3 (D), R24.2
unnamed: Q16.3 (D), R25.2
unnamed: Q17.3 (D), R26.2
unnamed: Q18.3 (D), R27.2
unnamed: Q19.3 (D), R28.2
unnamed: Q20.3 (D), R29.2
unnamed: Q21.3 (D), R30.2
unnamed: Q22.3 (D), R31.2
unnamed: Q23.3 (D), R32.2
unnamed: R1.1, U1.1
unnamed: R2.2, U2.1
unnamed: R3.1, U3.1
unnamed: R4.1, U4.1
unnamed: R5.1, U5.1
unnamed: R6.1, U6.1
unnamed: R8.1, U7.1
unnamed: R9.1, U8.1
unnamed: C2.2, U9.41 (ADC_VREF)

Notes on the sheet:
Horne
Zadne
Bocne

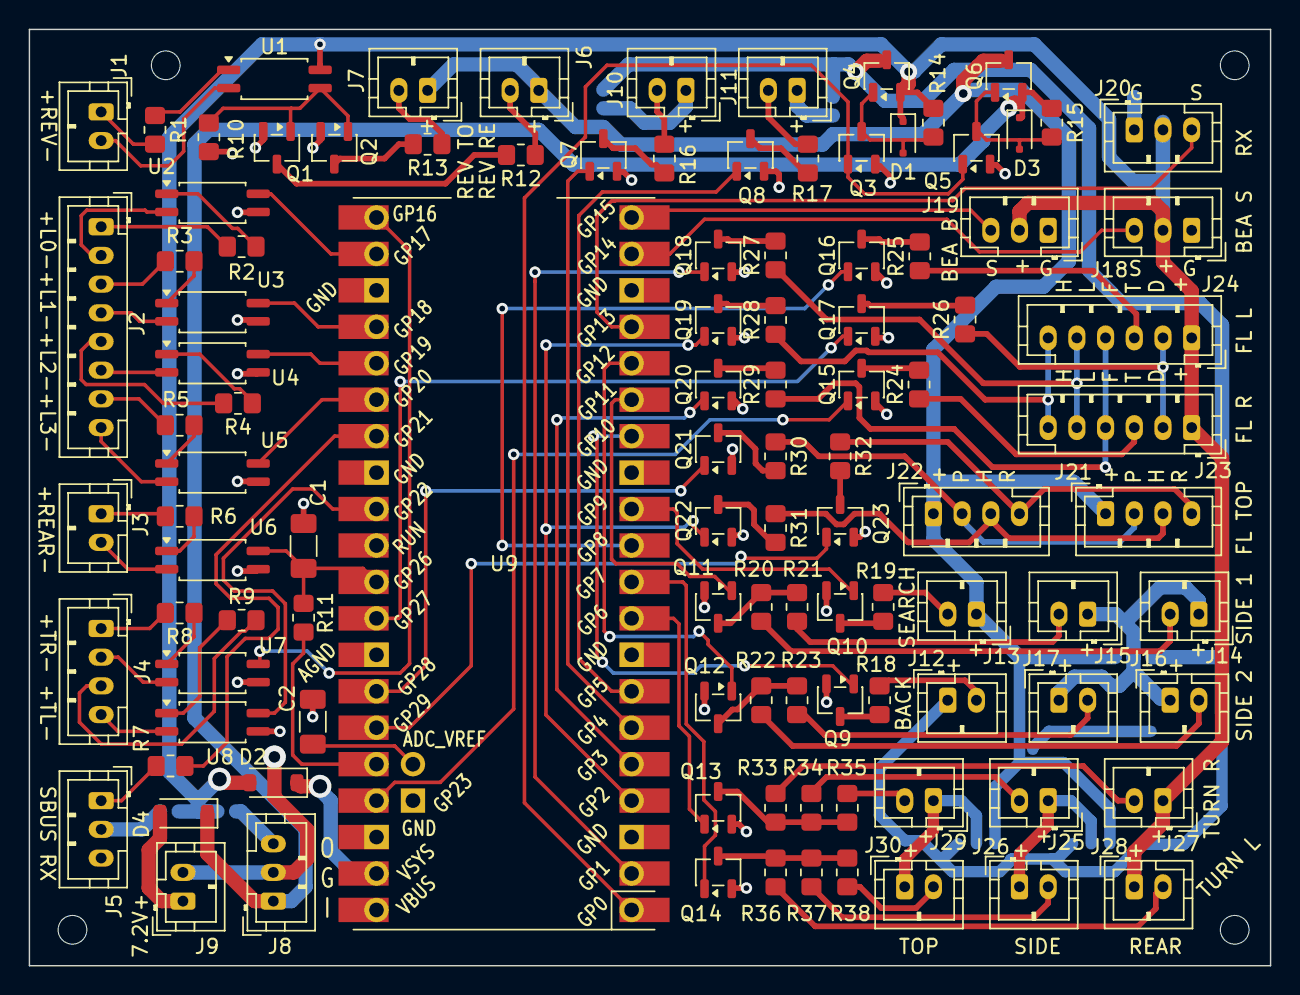
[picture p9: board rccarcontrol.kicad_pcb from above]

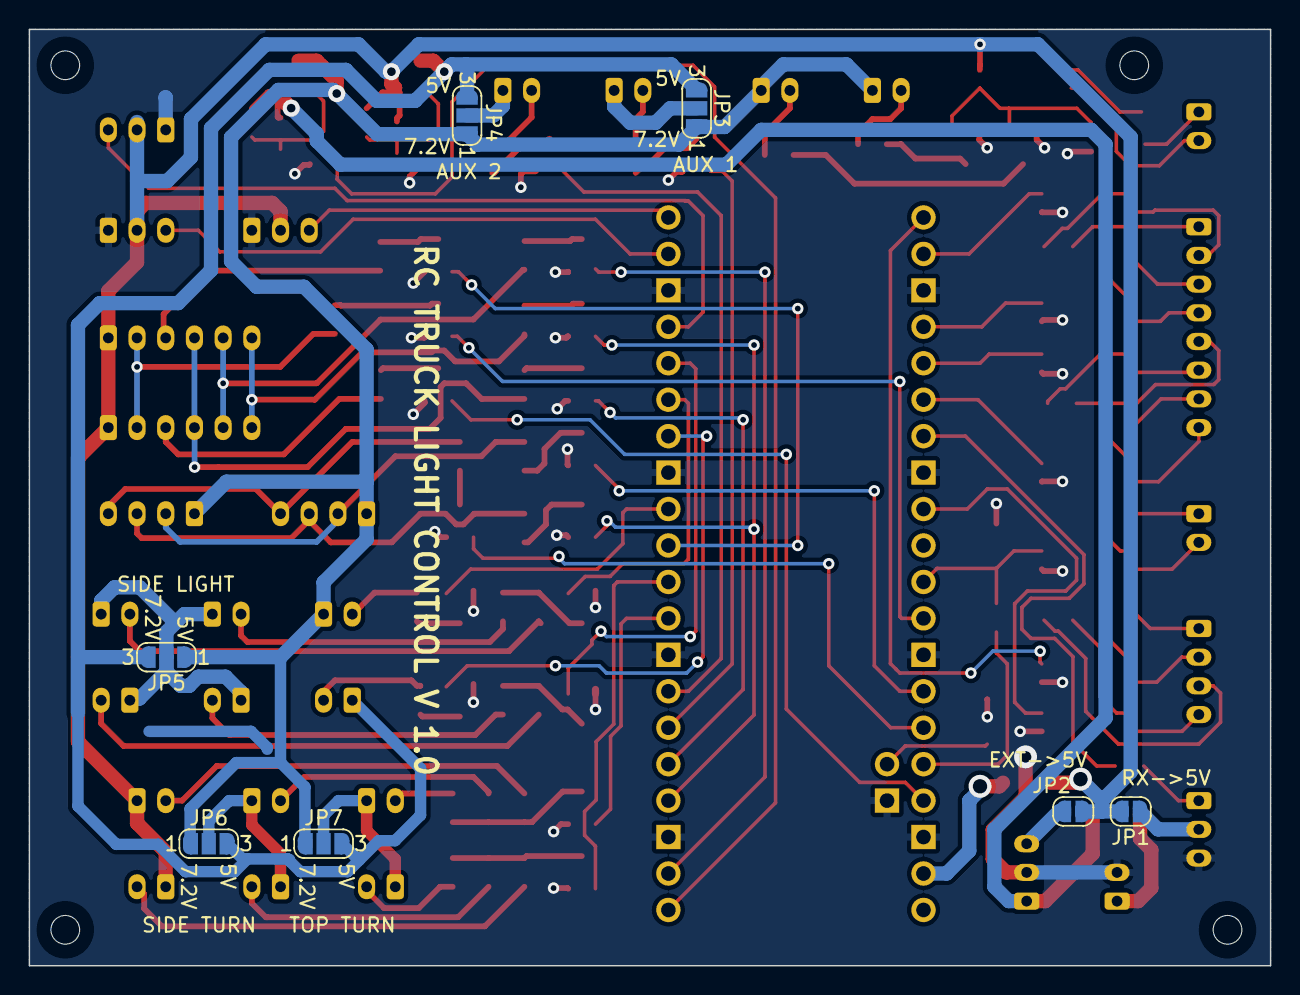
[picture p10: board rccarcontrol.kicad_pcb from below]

Board: 2 copper layers, 86.5 x 65.2 mm, 117 parts (7 on the bottom side), 116 nets.

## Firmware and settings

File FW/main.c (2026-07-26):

#include <stdio.h>
#include "pico/stdlib.h"
#include "hardware/clocks.h"
#include "hardware/pwm.h"
#include <stdlib.h>
#include <time.h>

#include "beacons.h"
#include "ibus.h"
#include "lights.h"
#include"rear_light.h"
#include "turn_light.h"
#include "to_mfc.h"
#include "aux1.h"

#define DBG


#define AUX_2_OUT_PIN 5     //pwm slice 2


#define LED_PIN 25




int main(void) {
    //stdout_uart_init();
//    stdio_usb_init();
    //printf("Starting...\n");
    gpio_set_function_masked((1<<LED_PIN),GPIO_FUNC_SIO);

    //pre AUX
    gpio_set_function_masked(
        (1<<AUX_2_OUT_PIN)|(1<<AUX_2_OUT_PIN),GPIO_FUNC_SIO);

    gpio_set_dir_out_masked((1<<LED_PIN) | (1<<AUX_2_OUT_PIN));

    gpio_put(LED_PIN,1);
    busy_wait_ms(500);
    gpio_put(LED_PIN,0);
    busy_wait_ms(500);
    gpio_put(LED_PIN,1);
    busy_wait_ms(500);
    gpio_put(LED_PIN,0);



    //init iBUS uart
    ibus_init();
    while (!ibus_data_valid()) {
        ibus_service();
    }
    rear_light_init();

    beacon_init();
    to_mfc_init();
    lights_init();
    turn_light_init();
    aux_1_init();





    while(1) {
        gpio_xor_mask(1<<AUX_2_OUT_PIN);
        ibus_service();

        lights_service();
        //****************************************
        //              zadne svetla
        //****************************************
        rear_light_service();

        //****************************************
        //              smerovky
        //****************************************
        turn_light_service();

        //beacon
        beacon_service();

        //to mfc
        to_mfc_service();

        //aux2
        aux_1_service();

    } //while 1

} //main

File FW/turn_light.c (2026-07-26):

//
// Created by all on 26. 11. 2025.
//

#include "turn_light.h"
#include "pico/stdlib.h"
#include "hardware/pwm.h"



#define TURN_L_FRONT_OUT_PIN 8   //predne smerovky pre kratky pulz
#define TURN_R_FRONT_OUT_PIN 23   //predne smerovky pre kratky pulz
#define TURN_R_PWM_OUT_PIN   6          //slice 3 A
#define TURN_L_PWM_OUT_PIN   7          //slice 3 B

#define TURN_LIGHT_R_21_IN_PIN 16
#define TURN_LIGHT_L_22_IN_PIN 22

#define TURN_LIGHT_R_MASK (1<<TURN_LIGHT_R_21_IN_PIN)
#define TURN_LIGHT_L_MASK (1<<TURN_LIGHT_L_22_IN_PIN)

#define TURN_LIGHT_PWM_INCREMENT 100
#define TURN_LIGHT_PWM_DECREMENT 50

#define TURN_LIGHT_INC_TIME_US 10000 //us
#define TURN_LIGHT_DEC_TIME_US 7500 //us
#define TURN_LIGHT_HOLD_TIME_US 100000 //us
#define TURN_LIGHT_FRONT_ON_TIME_USEC 100000
#define TURN_LIGHT_TOP_VALUE 2000

static uint pwm_slice_num_turn_light;  //smerovka PWM slice
static uint pwm_chan_num_turn_light_L;
static uint pwm_chan_num_turn_light_R;



static uint32_t turn_light_prev_state = TURN_LIGHT_L_MASK | TURN_LIGHT_R_MASK;  //L=1, R=1 - vypnute
static volatile bool turn_light_L_is_on = false;   //ze su smerovky zapnute
static volatile bool turn_light_R_is_on = false;   //ze su smerovky zapnute
static uint32_t f_turn_light_L_time;
static uint32_t f_turn_light_R_time;


//nastavit jas smeroviek 0...2000
void turn_light_L_set (uint16_t val) {
    pwm_set_chan_level(pwm_slice_num_turn_light, pwm_chan_num_turn_light_L, val);
}
void turn_light_R_set (uint16_t val) {
    pwm_set_chan_level(pwm_slice_num_turn_light, pwm_chan_num_turn_light_R, val);
}

void f_turn_light_L_on (void) {
    gpio_put(TURN_L_FRONT_OUT_PIN,true);
}
void f_turn_light_L_off (void) {
    gpio_put(TURN_L_FRONT_OUT_PIN,false);
}
void f_turn_light_R_on (void) {
    gpio_put(TURN_R_FRONT_OUT_PIN,true);
}
void f_turn_light_R_off (void) {
    gpio_put(TURN_R_FRONT_OUT_PIN,false);
}



void turn_light_init (void) {
    //init pins
    gpio_set_function_masked(
            (1<<TURN_L_FRONT_OUT_PIN)
            |(1<<TURN_R_FRONT_OUT_PIN)
            |(1<<TURN_LIGHT_R_21_IN_PIN)
            |(1<<TURN_LIGHT_L_22_IN_PIN)
            ,GPIO_FUNC_SIO);

    gpio_set_dir_in_masked(
        (1<<TURN_LIGHT_R_21_IN_PIN)
        |(1<<TURN_LIGHT_L_22_IN_PIN));

    gpio_set_dir_out_masked(
    (1<<TURN_L_FRONT_OUT_PIN)
        |(1<<TURN_R_FRONT_OUT_PIN));

    //enable pullups on turn_lights, lights inputs
    gpio_set_pulls(TURN_LIGHT_L_22_IN_PIN,true,false);
    gpio_set_pulls(TURN_LIGHT_R_21_IN_PIN,true,false);

    gpio_set_function_masked((1<<TURN_L_PWM_OUT_PIN) | (1<<TURN_R_PWM_OUT_PIN), GPIO_FUNC_PWM);

    pwm_slice_num_turn_light = pwm_gpio_to_slice_num(TURN_L_PWM_OUT_PIN); //L a R maju tu istu slice
    pwm_chan_num_turn_light_L = pwm_gpio_to_channel(TURN_L_PWM_OUT_PIN);
    pwm_chan_num_turn_light_R = pwm_gpio_to_channel(TURN_R_PWM_OUT_PIN);

    //smerovky
    //pre PWM 2000Hz: f = fsys/((1999+1) x clkdiv) = 125000000/((1999+1) x 31.25) = 2000
    //perioda = 0.5ms -> 2000
    //rozsah 0 - 0.5ms -> 0 - 2000
    //31.25 = 31 + 4/16   8bit int  + 4bit frac
    pwm_config c = pwm_get_default_config();
    pwm_config_set_clkdiv_int_frac4(&c,31,4);
    pwm_config_set_clkdiv_mode(&c, PWM_DIV_FREE_RUNNING);
    pwm_config_set_wrap(&c, 1999);
    pwm_config_set_output_polarity(&c,false,false);
    pwm_init(pwm_slice_num_turn_light, &c, true);
    turn_light_L_set(0);
    turn_light_R_set(0);
    f_turn_light_L_off();
    f_turn_light_R_off();

}

void turn_light_service (void) {
    uint32_t dt;
    static uint32_t ftL;
    static uint32_t ftR;
    static uint32_t tL;
    static uint32_t tR;
    static uint32_t valR;
    static uint32_t valL;
    static bool upL;
    static bool upR;

    //detekuje hranu a 1->0 potom necha zapnute urcity cas smerovky



    uint32_t turnlight_new_state = gpio_get_all();
    turnlight_new_state &= TURN_LIGHT_L_MASK | TURN_LIGHT_R_MASK;
     uint32_t tmp = turn_light_prev_state ^ turnlight_new_state;  //ak je zmena = tmp = 1
    tmp &= turn_light_prev_state;    //predchadzajuci stav ak je 1 tak toto je pozadadovana hrana 1->0
    turn_light_prev_state = turnlight_new_state;


    if (!turn_light_L_is_on && (tmp & TURN_LIGHT_L_MASK)) {
        //turnlight_L switched on
        turn_light_L_is_on = true;
        ftL = time_us_32() + TURN_LIGHT_FRONT_ON_TIME_USEC ;
        f_turn_light_L_on();

        valL = TURN_LIGHT_PWM_INCREMENT;
        turn_light_L_set(valL);
        tL = time_us_32() + TURN_LIGHT_INC_TIME_US;
        upL = true;
    }
    if (!turn_light_R_is_on && (tmp & TURN_LIGHT_R_MASK)) {
        //turnlight_R switched on
        turn_light_R_is_on = true;
        ftR = time_us_32() + TURN_LIGHT_FRONT_ON_TIME_USEC ;
        f_turn_light_R_on();

        valR = TURN_LIGHT_PWM_INCREMENT;
        turn_light_R_set(valR);
        tR = time_us_32() + TURN_LIGHT_INC_TIME_US;
        upR = true;
    }



    if (turn_light_L_is_on) {
        dt = (time_us_32() - ftL);
        if ((int32_t) dt >= 0) {
            f_turn_light_L_off();
        }

        dt = (time_us_32() - tL);
        if ((int32_t) dt >= 0) {
            if (upL) {
                valL += TURN_LIGHT_PWM_INCREMENT;
                turn_light_L_set(valL);
                if (valL == TURN_LIGHT_TOP_VALUE) {
                    tL += TURN_LIGHT_HOLD_TIME_US;
                    upL = false;
                }
                else {
                    tL += TURN_LIGHT_INC_TIME_US;
                }
            }
            else {
                valL -= TURN_LIGHT_PWM_DECREMENT;
                turn_light_L_set(valL);
                if (valL == 0) {
                    turn_light_L_is_on = false;
                }
                else {
                    tL += TURN_LIGHT_DEC_TIME_US;
                }
            }
        }
    }


    if (turn_light_R_is_on) {
        dt = (time_us_32() - ftR);
        if ((int32_t) dt >= 0) {
            f_turn_light_R_off();
        }

        dt = (time_us_32() - tR);
        if ((int32_t) dt >= 0) {
            if (upR) {
                valR += TURN_LIGHT_PWM_INCREMENT;
                turn_light_R_set(valR);
                if (valR == TURN_LIGHT_TOP_VALUE) {
                    tR += TURN_LIGHT_HOLD_TIME_US;
                    upR = false;
                }
                else {
                    tR += TURN_LIGHT_INC_TIME_US;
                }
            }
            else {
                valR -= TURN_LIGHT_PWM_DECREMENT;
                turn_light_R_set(valR);
                if (valR == 0) {
                    turn_light_R_is_on = false;
                }
                else {
                    tR += TURN_LIGHT_DEC_TIME_US;
                }
            }
        }
    }

}
